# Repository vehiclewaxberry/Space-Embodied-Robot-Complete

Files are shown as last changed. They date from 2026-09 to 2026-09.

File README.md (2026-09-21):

# 航天服务星具身智能机械臂机器人

**Space Service Robot with Embodied Intelligence**

面向在轨服务的 12U 立方星服务星 + B601 六自由度机械臂的完整数字样机、机械/电气设计与自由漂浮动力学证据库。

*A complete digital prototype, mechanical/electrical design package, and free-floating dynamics evidence base for a 12U CubeSat servicing spacecraft with a B601 6-DOF manipulator.*

---

## 项目定位 / Scope

这是一个**在轨服务空间机器人学的科研项目**，同时承载长期硬件研发。两条线互为约束：

- **研究线** —— 面向抓取后可稳定性的**预见式具身抓取**。核心问题：在自由漂浮、刚柔耦合、目标非合作的条件下，捕获策略的可行域由哪些物理边界决定。
- **工程线** —— 可装配、可参数化、可验证的 12U 服务星与 B601 机械设计，作为研究结论的物理载体与参数来源。

研究产出以**机器裁决证据**（`*_gate_check.json`）与论文结构为组织形式，而非演示件。论文规划入口见 [`10_research/paper1_architecture.md`](10_research/paper1_architecture.md)（Paper 1 = 柔性耦合捕获任务可行域），问题树见 [`10_research/research_questions/`](10_research/research_questions/)。

*This is a research project in on-orbit-servicing space robotics, carried alongside long-term hardware development. The research line studies predictive embodied grasping for post-capture stabilizability — specifically, which physical boundaries determine the feasible domain of capture strategies under free-floating, rigid-flexible coupled, non-cooperative conditions. Outputs are organised as machine-adjudicated evidence and paper structure, not demos.*

> **关于历史来源**：项目起源于中国研究生未来飞行器创新大赛（第十二届）。比赛记录、机器 Gate 与负结果作为**历史证据**原位保留，但**比赛期限与比赛交付不再构成研究议程、工程验收门槛或授权 Gate**。请勿据历史比赛记录升级当前结论。

### 任务设定 / Mission

| 项 | 值 |
|---|---|
| 服务星 | 12U CubeSat 平台 |
| 机械臂 | B601，6R 串联构型 |
| 目标 A | 150 kg 翻滚空间碎片 |
| 目标 B | 22 kg 非合作目标星 |
| 动力学工况 | 自由漂浮（free-floating），基座不固定 |
| 研究线 | 面向抓取后可稳定性的预见式具身抓取 |

---

## 仓库导航 / Repository layout

八个业务域，根目录不再建立平行的 `src/` `docs/` `results/` 树。

| 目录 | 内容 |
|---|---|
| [`01_project/`](01_project/) | 项目入口、治理、协作原件、历次工作包记录 |
| [`10_research/`](10_research/) | 研究问题树、方法、合同、知识库、论文材料 |
| [`20_engineering/`](20_engineering/) | **CAD、电气、BOM、参数、接口与设计证据** |
| [`30_simulation/`](30_simulation/) | 模型、程序、测试、原始结果、机器裁决 |
| [`40_evidence/`](40_evidence/) | 图表、媒体、离线展示 |
| [`50_literature/`](50_literature/) | 题录、阅读卡、BibTeX |
| [`70_tools/`](70_tools/) | 编目、展示、校验工具 |
| [`80_third_party/`](80_third_party/) | 外部来源登记与许可（见 [NOTICE.md](NOTICE.md)） |

全项目导航入口：**[PROJECT_MAP.md](PROJECT_MAP.md)**

---

## 协作者快速上手 / Getting started for collaborators

仓库含 **13 GB Git LFS 内容**（7,328 个对象，主要是 CAD）。**克隆方式选错会出问题**，请按下面来。

### ① 先装 Git LFS —— 不装的话你拿到的是一堆占位符

这是最常见的坑：没装 LFS 就 `git clone`，所有 CAD 文件会变成约 130 字节的指针文本。**文件名看着都在，但一个都打不开。**

```bash
git lfs install
```

*Install [Git LFS](https://git-lfs.com/) first. Without it every CAD file clones as a ~130-byte pointer stub — the filenames all look right, but nothing opens.*

### ② 推荐：先不拉 CAD，按需取件

完整克隆会下载 13 GB，**消耗仓库的 LFS 带宽配额**；配额耗尽后**所有人**的 LFS 下载都会被阻断。除非确实需要全部 CAD，否则请用：

```bash
GIT_LFS_SKIP_SMUDGE=1 git clone https://github.com/vehiclewaxberry/Space-Embodied-Robot-Complete.git
```

这样能拿到全部代码、文档、仿真结果与机器裁决（约 256 MB），CAD 先留作指针。需要某个具体部件时再单独拉：

```bash
# 例：只取最新整星总装
git lfs pull --include="20_engineering/SERVICE_STAR_CORE_INSTALLATION_R6H_20260920/**"

# 例：只取某一批 STEP
git lfs pull --include="20_engineering/SERVICE_STAR_HARDWARE_COMPACT_20260921/**"
```

*Full clones pull 13 GB and consume the repository's shared LFS bandwidth quota; once it is exhausted, LFS downloads are blocked for everyone. Prefer the skip-smudge clone above and fetch only what you need.*

### ③ 确实需要全部 CAD 时

```bash
git clone https://github.com/vehiclewaxberry/Space-Embodied-Robot-Complete.git
```

请先知会仓库所有者——这一次操作会占用约 13 GB 带宽配额。

### 打开 CAD 需要什么

| 格式 | 仓库内文件数 | 需要的软件 |
|---|---|---|
| `.STEP` | 3,404 | **任意 CAD 软件**（FreeCAD、Fusion、CATIA、NX…）— 没有 SolidWorks 就用这个 |
| `.SLDASM` / `.SLDPRT` | 6,233 | SolidWorks 2024 及以上 |
| `.FCStd` | 89 | FreeCAD |
| `.glb` / `.stl` | 873 | 任意三维查看器（仅可视化，非设计源） |

全部 CAD 合计 13 GB LFS（7,328 个去重对象——同内容的文件共享一份存储，所以实际下载量小于按文件数的估计）。

---

## 研究线 / Research programme

### 六层架构

研究按六层组织，**各层分别取证，不由某层结论覆盖其它层**：

| 层 | 职责 | 状态 |
|---|---|---|
| **L0** | 任务可行性 / 策略 | 已实现（`sim_10`、`sim_12`） |
| **L1** | SAFE 证据核 | `SAFE-00` 47/47 PASS，`review_status=PENDING_REVIEW` |
| **L2** | 确定性控制 | `CTRL-01/02`，带 PROVISIONAL 范围限定 |
| **L3** | 刚柔世界模型 | `sim_11` v1.1，含占位参数 |
| **L4** | 具身候选生成 | 规划态，未实施 |
| **L5** | 地面验证 | H0–H3 规划态，未实施 |

导航：[`10_research/00_project_architecture/`](10_research/00_project_architecture/)

### 论文线

| 论文 | 主题 | 状态 |
|---|---|---|
| **Paper 1** | 柔性耦合捕获任务可行域 | 证据/查新收口中，结构见 [`paper1_architecture.md`](10_research/paper1_architecture.md) |
| **Paper 2** | 接触带宽 / 保真度 | 候选，未启动 |

问题树 Q1–Q6、理论假设与主张-证据关系见 [`10_research/research_questions/`](10_research/research_questions/)、[`theory_graph/`](10_research/theory_graph/)、[`contribution_map/`](10_research/contribution_map/)。

文献主清单：[`50_literature/references/manifest.yaml`](50_literature/references/manifest.yaml)（44 篇 PDF / 29 张阅读卡；**PDF 全文因版权不随仓库分发**，按 manifest 自行获取）。

### 规划态支线（**尚未授权实施**）

`BRIDGE-UT` 带界不确定目标操作、`Q6-L1` 预制接口装配、On-Orbit Assembly Wave A、Physics-Gated Agent、ROM、VLA —— 这些目录存在**不等于**实施完成或已授权。请按各目录内的具名合同理解其范围。

---

## 当前硬件基线 / Current hardware baseline

这是接手后续开发时**首先要看的**部分。

| 要做的事 | 入口 |
|---|---|
| 四系统硬件主设计（机械 / 电气线束 / 能源热控 / 动力推进） | [`20_engineering/SERVICE_STAR_HARDWARE_COMPACT_20260921/`](20_engineering/SERVICE_STAR_HARDWARE_COMPACT_20260921/) |
| **最新整星总装（数字样机）** | [`SERVICE_STAR_CORE_INSTALLATION_R6H_20260920/native/SERVICE_STAR_SERVICE_R6H.SLDASM`](20_engineering/SERVICE_STAR_CORE_INSTALLATION_R6H_20260920/native/) |
| 电气选型当前指针 | [`20_engineering/SERVICE_STAR_ELECTRICAL_LATEST.json`](20_engineering/SERVICE_STAR_ELECTRICAL_LATEST.json) |
| R7 安装布局草案（**未完成项**） | [`20_engineering/SERVICE_STAR_AUX_STOP_INSTALLATION_R7_20260921/`](20_engineering/SERVICE_STAR_AUX_STOP_INSTALLATION_R7_20260921/) |
| 上游机械来源（星体本体） | [`20_engineering/service_robot_wp03_spacecraft_body_r1/`](20_engineering/service_robot_wp03_spacecraft_body_r1/) |

**读法约定**：选型候选与未安装草案分别看待，**不按目录日期推定完工**。R6H 原件保留，没有回退为早期 WP03。

### CAD 格式说明

原生件为 SolidWorks（`.SLDPRT` / `.SLDASM`），中性交换格式为 `.STEP`，二者均通过 Git LFS 存储。**克隆方式与所需软件见上文[协作者快速上手](#协作者快速上手--getting-started-for-collaborators)**——直接 `git clone` 而未装 LFS 会拿到占位符而非真实 CAD。

---

## 已验证的核心结果 / Verified results

以下数值来自各模块的**机器裁决 JSON**（`*_gate_check.json`），引用时请勿改动。注意：**测试 PASS ≠ 科学 Gate PASS**。

| 编号 | 结论 | 关键数值 |
|---|---|---|
| `sim_05` | B601 自由漂浮，臂运动致基座姿态扰动 | 峰值 **19.20°**；动量守恒 7.3e-17 |
| `sim_06` | 矢量式捕获冲量——**捕获 ≠ 消旋** | 碎片 @3°/s → 捕获后 3.06°/s |
| `sim_07` | ANCF 柔性帆板，点捕获激振 vs 刚性锁定 | ≈ **92×**；振铃 37–75 s |
| `sim_08` | 150 kg 碎片消旋**必须用推力器** | `\|H_c\|` = 3.65 N·m·s = **12×** 轮组容量 |
| `sim_10` | 任务可行域 9000 点四门 fail-closed 扫描 | 裁决 `SIM10_GATES_PASS` |
| `sim_11` v1.1 | 刚柔耦合，有限接触窗口 | `SIM11_GATES_PASS_WITH_PROVISIONAL_PARAMS` |
| `sim_12` Phase1 | 16 例策略证明集——**最优捕获策略是 binding gate 的函数** | `SIM12_PHASE1_GATES_PASS` |
| `SAFE-00` | 运行时安全门 | 47/47 PASS，七绕过面全封 |

### 对后续在轨服务开发的直接含义

1. **基座扰动不可忽略**：自由漂浮下 19.20° 的姿态耦合意味着臂规划必须与姿态控制联合求解。
2. **捕获与消旋是两个问题**：捕获冲量不消除目标角动量；150 kg 级目标的消旋超出轮组容量一个数量级。
3. **柔性帆板是激振主源**：点捕获相对刚性锁定放大约 92 倍，接触策略必须考虑帆板模态。
4. **策略选择依赖于约束边界**：不同 binding gate 下最优策略不同（S1 / S3a / ABORT）。

---

## 明确的未完成项与占位参数 / Known gaps

本节是**刻意保留**的。项目约定：负结果、UNKNOWN 与占位参数不得被整理或总结所掩盖。

| 项 | 状态 | 影响 |
|---|---|---|
| **帆板质量 0.348 kg** | **占位值**。真实面密度 2–5 kg/m²，差 5–10 倍 | 真实参数下「柔性反馈可忽略」的结论**可能翻转**。当前最大硬伤 |
| **接触窗口 `T_c` = 20 ms** | `PROVISIONAL`，待 B601 夹爪实测 | 需替换 `scene_A2_capture.yaml` 后重跑带宽口径 Gate |
| 帆板模态参数 | 占位 | 同上 |
| `e15` ANCF 认证 | 交叉求解最大差 5.64% > 5% 门槛 → `REPEAT_ANCF_CERTIFICATION` | 全耦合新模型须重过该 Gate |
| `FLEX` | `UNKNOWN`，不入 `sim_10` 判据 | 可行域为**刚体边界** |
| R7 安装布局 | 草案，未安装 | 不得按日期推定完工 |
| `CTRL-02` 姿态分账 | `PASS_WITH_PROVISIONAL_SCOPE` | 硬件有效稳定性 `NOT_EVALUATED_NO_ACTUATOR_DYNAMICS` |

> 引用控制类结论时必须带限定语：「**在冻结增益与预注册轨迹下**」。

---

## 证据与结论约定 / Evidence conventions

这套约定是项目的核心工程文化，接手者请遵守：

- **科学结论只认机器裁决 JSON**（`*_gate_check.json`），不认文档摘要。
- **测试通过 ≠ 科学 Gate 通过**。
- 每个 `sim_XX` / `eXX` 模块自带 `src/` `tests/` `results/` `docs/`，自包含。
- 失败、`UNKNOWN`、受限结果**留在原拥有者目录**，不被后续工作覆盖。
- 不同模型与版本的结果**不互相覆盖**，导航不汇总为单一通过状态。
- 目录同名、同日期或位于 `archive/` `_work/` **不足以证明文件无用**。

---

## 复现 / Reproducing

各仿真模块自包含。典型流程：

```bash
cd 30_simulation/sim_11_coupled_dynamics
python -m pytest tests/          # 模块测试
python src/run_all.py            # 重跑场景与 Gate
cat results/sim_11_gate_check.json   # 读机器裁决
```

> **注意**：`control_01` / `control_02` 的 `run_all.py` 会**覆写** `results/` 下的 gate JSON。运行前请先 snapshot，运行后 restore。

---

## 第三方 / Third-party

本仓库**不转发**上游第三方代码库。所使用的外部平台（Basilisk、Exudyn、Chrono、SPART、SpaceDyn、Astrobee、OpenVLA、openpi 等）及其许可证登记于 **[NOTICE.md](NOTICE.md)**，请从各自上游获取。

外部参考 CAD 与供应商模型的来源、版本与许可见 [`80_third_party/README.md`](80_third_party/README.md)。

---

## 引用 / Citation

见 [CITATION.cff](CITATION.cff)。

---

## 许可 / License

见 [LICENSE](LICENSE)。第三方组件各自适用其上游许可，见 [NOTICE.md](NOTICE.md)。

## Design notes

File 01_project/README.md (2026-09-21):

# 项目工作与治理

<!-- WORKSPACE_NAV_START -->
**2026-09-21 目录整理入口：** [本域用途与归档总览](../01_project/governance/WORKSPACE_ORGANIZATION_20260921/WORKSPACE_INDEX.html?domain=01_project) · [全项目导航](../PROJECT_MAP.md)。历史来源和证据原位保留；本轮整理不改变设计或科学结论。
<!-- WORKSPACE_NAV_END -->

2026-09-06 整理。本域保存工作入口、治理记录、人工输入与审阅会话；`competition/` 同时包含历史比赛材料和后续工程工作记录。

- [项目总地图](../PROJECT_MAP.md)：八业务域路径导航。
- [当前整理会话](competition/SERVICE_ROBOT_MECHANICAL_CONSOLIDATION_20260905/CURRENT_candidate.md)：问题、依赖、运行与文件整理账本。
- [R2 来源指针](current/CURRENT_RELEASE_POINTERS_V1.yaml)与[来源关系索引](current/PROJECT_CURRENT_AUTHORITY_V1.yaml)：定位原始记录；派生导航不替代机器证据。
- [工程候选入口](../20_engineering/README.md)：WP03 服务星候选与工程来源。
- [工作与历史材料](competition/README.md)、[治理迁移记录](governance/README.md)、[人工输入](inbox/)：按日期和对象阅读。
- [根层历史综述](competition/archive/ROOT_HISTORY_20260729_20260810.md)：原根总结与入驻说明已合并；[入驻独有图示](competition/archive/onboarding_20260729/)及[历史收尾记录](competition/archive/90_competition_closeout/)保留原字节。

本域不承载科学仿真结果。`current/` 的日期快照和旧任务许可保留原语境，不能把历史“当前”当作今天的授权。原重复导航段已吸收，整理前字节保存在共享 SQLite。

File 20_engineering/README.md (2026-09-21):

# 工程设计、参数与装配入口

<!-- WORKSPACE_NAV_START -->
**2026-09-21 目录整理入口：** [本域用途与归档总览](../01_project/governance/WORKSPACE_ORGANIZATION_20260921/WORKSPACE_INDEX.html?domain=20_engineering) · [全项目导航](../PROJECT_MAP.md)。历史来源和证据原位保留；本轮整理不改变设计或科学结论。
<!-- WORKSPACE_NAV_END -->

整理日期：2026-09-21。本域保存当前机械候选、被引用的上游模型、参数和历史验证来源。先按以下入口阅读；目录名中的 RELEASE、FINAL 或版本号不能独自证明工程完成或可制造。

**硬件设计的精简工作入口为 [SERVICE_STAR_HARDWARE_COMPACT_20260921](SERVICE_STAR_HARDWARE_COMPACT_20260921/README.md)。其中当前服务态总装以R6H为准，保留后续水平安装集成，并包含机械、电气线束、能源热控和推进主文件。原R6H总装未删除；WP03属于上游机械基线，不能替代R6H。整理状态与公开边界见包内说明。**

## 当前设计与装配

| 内容 | 入口与职责 |
|---|---|
| 当前硬件精简副本 | [硬件设计总入口](SERVICE_STAR_HARDWARE_COMPACT_20260921/README.md)：R6H机械总装及电气、热控、推进主设计 |
| 当前机械源总装 | [R6H原生服务态总装](SERVICE_STAR_CORE_INSTALLATION_R6H_20260920/native/SERVICE_STAR_SERVICE_R6H.SLDASM)、[现行指针](SERVICE_STAR_CORE_INSTALLATION_LATEST.json) |
| 上游完整机械基线 | [WP03](service_robot_wp03_spacecraft_body_r1/README.md)：星体、完整 B601、双翼、保持器、设备接口和总装图册；保留其来源职责 |
| 装配和实际交付范围 | [装配程序](service_robot_wp03_spacecraft_body_r1/ASSEMBLY_SEQUENCE.md)、[交付回执](service_robot_wp03_spacecraft_body_r1/results/DELIVERY_RECEIPT.json) |
| 仍被 WP03 读取的上游 | [WP01](service_robot_wp01_20260905/)与[WP02](service_robot_wp02_20260905/)：机械臂、根框、接触、线束及检查输入；不是三套可互换的当前整星 |
| 参数和接口 | [config](config/)、[design_inputs](design_inputs/)、[parameter_registry](parameter_registry/)：按各模型所属版本使用 |
| 原生 CAD 和厂家/accepted 来源 | [cad](cad/)；保留 donor、冻结基线和原生装配引用关系 |
| 审阅与系统材料 | [design_review](design_review/)、[system_design](system_design/)、[automation](automation/) |

## R2 与早期版本的职责

- [R2 原终裁](MECHANICAL_ENGINEERING_RELEASE_R2/00_RELEASE_GATE.json)与[基线清单](MECHANICAL_ENGINEERING_RELEASE_R2/01_BASELINE_MANIFEST.json)独立描述 R2；不被 WP03 候选覆盖。
- R2 后续具名记录由[发布来源指针](../01_project/current/CURRENT_RELEASE_POINTERS_V1.yaml)定位，包括 [ODR-60 Option A](MECHANICAL_ENGINEERING_RELEASE_R2/_work/odr/ODR60_OPTION_A_EXECUTION_CLOSURE_V1/results/ODR60_OPTION_A_EXECUTION_CLOSURE_GATE_V1.json)。
- `F3*`、`F4*`、`F5*` 的版本树包含 donor、失败几何、冻结输入和验证链。旧导航所称 M7“当前”仅指当时记录；其 [V5 continuation Gate](F3R2_M7_MECHANICAL_FINAL_DESIGN_CLOSURE_V1/ecr_b601_harness_rated_envelope/15_loop_continuation_v5/MECHANICAL_LOOP_ENGINEERING_CONTINUATION_GATE_V5.json)原结论为 HOLD，不覆盖本页 WP03 入口。
- 27 个 `_MFINAL_G0_SMOKE_*` 目录共 83 个 JSON，是旧会话/连接核查回执；已有历史脚本按路径读取，集中在索引中作为回执组查看。目录多不表示存在 27 套机械设计，本轮保持路径和证据身份。
- [Stage 1 早期库](stage1_spacecraft_layout/README.md)包含早期参考、布局需求、坐标和预算模板。已合并三组中英文需求、一份建库说明和一份英文资产镜像；适配器英文原件因 A4 清单固定 SHA 保留。
- [原根结构材料](system_design/legacy_root_structure/)保留合同原值和独立职责。

## 缓存、压缩包与重复件为什么有些保留

WP01/02/03 的 `__cadgen__` 编目分别为 4,132 / 1,368 / 8,454 文件，合计 **13,954**。这些是 CAD 可视化/拓扑派生物及诊断来源，数量不等于设计零件数。已查 WP03 的 Python 生成视图包与 STEP 导入视图包具有不同 stepHash 和网格参数；[包络方法比较](service_robot_wp03_spacecraft_body_r1/results/BOUNDING_METHOD_COMPARISON.json)固定了 assembly、542 个组件 GLB 和 topology GLB 的输入身份。交付汇总与图册脚本也读取这些包，已有 PNG 或 STEP 不足以证明它们全部可删除。

工程域剩余 11 个 ZIP 为 9 个 B51 授权/阶段包、1 个原终端基线包、1 个 V5 失效模型隔离包。它们不是 11 份同字节文件；其中已检查的基线包和隔离包被回执固定 SHA/范围，保留原始包。来源许可、O11/O13、PHASE0 等相同正文的 donor 副本也有 source/copy 分别绑定的情形，不能只保留一份后仍声称原验证链完整。

Route-C V8 第 1 回路简报的冗余副本已删除，保留 [规范简报](MECHANICAL_ENGINEERING_RELEASE_R2/route_c/B601_ROUTE_C_V8_CAD_BRIEF.md)；该回路的被拒绝模型、构建器、JSON 和网格证据仍在原处。

已从 WP01/WP02/WP03 删除 159 个对应源码存在、文件头匹配且未发现固定输入绑定的 Python 字节码，源码均保留。审阅的其余 197 个缓存保持原位；12 个删除文件后已空的缓存目录因自动审批拒绝删除而保留。未执行冷启动或重新编译来宣称重建通过。

## 全域记录

[统一整理入口](../01_project/competition/SERVICE_ROBOT_MECHANICAL_CONSOLIDATION_20260905/CURRENT_candidate.md)连接逐文件目录、处置理由、删除映射及原始字节备份。对目录和文件用途的登记不等于逐件打开 CAD、验证全部动态引用或全文专业精读；这些范围在账本中分别标记。

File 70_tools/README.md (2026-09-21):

# 项目整理、研究环境与展示工具

<!-- WORKSPACE_NAV_START -->
**2026-09-21 目录整理入口：** [本域用途与归档总览](../01_project/governance/WORKSPACE_ORGANIZATION_20260921/WORKSPACE_INDEX.html?domain=70_tools) · [全项目导航](../PROJECT_MAP.md)。历史来源和证据原位保留；本轮整理不改变设计或科学结论。
<!-- WORKSPACE_NAV_END -->

导航整理：2026-09-06。本域保存非业务结论型工具；工具运行记录与原始科学、工程结论分开。

- [全项目文件目录工具](mechanical_asset_index/scan_service_robot_assets.py)：使用 `--full-project` 转入[静态目录解析器](mechanical_asset_index/full_project_catalog.py)，登记文件、依赖、阅读范围与整理处置。
- [统一目录数据库](../01_project/competition/SERVICE_ROBOT_MECHANICAL_CONSOLIDATION_20260905/runs/loop0_20260905/screening/full_project_catalog.sqlite)：保存本轮目录、阅读记录、逐文件审阅、操作及压缩前件备份；[会话入口](../01_project/competition/SERVICE_ROBOT_MECHANICAL_CONSOLIDATION_20260905/CURRENT_candidate.md)。
- [来源索引构建器](current_authority_index/README.md)：生成 R2 等既有来源的派生导航。
- [研究仪表板](research_dashboard/README.md)与[可视化源码](project_visualization/src/)：构建离线展示，不新增科学结论。
- [科研环境说明](research_env/README.md)：工具链的有日期记录，软件能力及安装情况按实际环境核实。

在项目根目录运行全项目静态编目，或读取已存摘要：

```powershell
python -B 70_tools/mechanical_asset_index/scan_service_robot_assets.py --full-project
python -B 70_tools/mechanical_asset_index/scan_service_robot_assets.py --full-project --summary
```

这些入口不执行仿真或 CAD 生成。文件整理的操作范围和结果由本轮会话及数据库记录，不由旧索引中的删除候选数量决定。

- [根级 F3R2 历史脚本](legacy_f3r2_root_scripts/)已归入本域；它们与发布包 99_tools 的同名版本不同，固定输入哈希保留。旧辅助模块缺失仍是已知历史问题。
- [本次根目录合并工具](mechanical_asset_index/consolidate_root_layout.py)与 SQLite `root_layout_actions` 保存已执行映射；该工具为已完成的一次性操作，不作为日常 CAD/仿真入口。`--full-project` 是原编目快照的续跑，不是目录迁移后的全新扫描。

## 子目录职责

| 子目录 | 用途与保留范围 |
|---|---|
| [current_authority_index/](current_authority_index/README.md) | 派生来源导航生成器及其独立测试；不拥有机器结论 |
| [mechanical_asset_index/](mechanical_asset_index/) | 本次全项目编目与整理工具；由主线程维护 |
| [legacy_f3r2_root_scripts/](legacy_f3r2_root_scripts/) | 已归位的历史 F3R2 脚本，固定输入与旧版本差异保留 |
| [preauthorization_readiness/](preauthorization_readiness/unified_r2_v2/README.md) | Unified R2 历史预执行探测与就绪性检查，保留对应源码与记录 |
| [project_visualization/](project_visualization/) | VIZ 离线展示源码与独立验证；[历史比赛启动说明](../10_research/competition_convergence/launch_manifest.md) |
| [research_dashboard/](research_dashboard/README.md) | P0 历史研究证据集成；报告和输入/产物清单相互绑定，原位保留 |
| [research_env/](research_env/README.md) | 有日期的软件环境与工具能力记录，不是科学参数或当前安装保证 |

旧域说明中的重复导航已并入本页。报告构建、可视化和回放从本域进入；本轮不重写工具包的冻结 Gate、结果 manifest 或输入哈希。

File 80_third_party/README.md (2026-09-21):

# 第三方代码、供应商与参考资源

<!-- WORKSPACE_NAV_START -->
**2026-09-21 目录整理入口：** [本域用途与归档总览](../01_project/governance/WORKSPACE_ORGANIZATION_20260921/WORKSPACE_INDEX.html?domain=80_third_party) · [全项目导航](../PROJECT_MAP.md)。历史来源和证据原位保留；本轮整理不改变设计或科学结论。
<!-- WORKSPACE_NAV_END -->

导航整理：2026-09-06。本域保存外部代码、参考平台和供应商资源；外部来源与项目自有设计、计算结果分开。

- [外部参考工程和资料](external/)：按来源、版本和实际消费者定位。
- [供应商及第三方仓库](vendor/)：保留各仓库的许可证、独立版本历史和本地修改信息。
- [文献题录](../50_literature/README.md)：论文进入文献库；[工程定义](../20_engineering/README.md)负责本项目使用这些资料形成的设计。

许可证与 NOTICE 以对应来源中的实际文件为准；旧导航所述待建目录不视为已存在。第三方参考或演示结果不自动成为本项目结论。

旧导航中的 `notices/` 是待建的项目随行许可证、NOTICE 与来源哈希记录目录；该规划不代表目录或第三方源资产副本已经存在。

## BIRDSX-CAD 来源入口

优先使用 [birds/BIRDSX-CAD](external/spacecraft_layout_refs/birds/BIRDSX-CAD/) 的完整来源与 [README](external/spacecraft_layout_refs/birds/BIRDSX-CAD/README.md)。[birdsx/BIRDSX-CAD](external/spacecraft_layout_refs/birdsx/BIRDSX-CAD/) 保留为已有消费者使用的历史镜像，两处属于同一上游来源，不应计作两份独立工程参考。

2026-09-06 本地核验：两库 HEAD 均为 `36bceeacc9f899477f2f10e36f8a65f7b58cb4ed`，共有的 26 个工作树文件逐项 SHA-256 相同；`birds` 工作树完整且干净，`birdsx` 存在原有 `README.md` 删除状态。两库的独立 `.git` 索引与日志有差异，因此各自版本历史和原有工作树状态完整保留。许可证见 [BIRDSX-CAD/LICENSE](external/spacecraft_layout_refs/birds/BIRDSX-CAD/LICENSE)，历史镜像内也保留原许可证。

## LibreCube 接口参考范围

LibreCube 用作模块化开源空间系统的接口思想参考。原第一阶段说明约定暂不深入代码，仅在需要 OBC、EPS 或模块接口定义时再展开；这是原阶段的范围记录，不构成新的实施授权。现有 [LC2102 源库](external/spacecraft_layout_refs/librecube/LC2102/) 与其许可证、版本历史继续保留。

2026-09-06 将原 `external/spacecraft_layout_refs/librecube_notes/README.md` 的三条说明并入本节，并移除该空目录；原文完整字节保存在整理账本的 SQLite 快照中。此次元数据与目录核验不等同于第三方代码、CAD 原生内部引用或论文全文的专业审查。

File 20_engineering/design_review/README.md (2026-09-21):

# Mechanical Design Reviews

本目录保存机械系统设计评审包，不保存 SolidWorks 原生模型，也不替代科学 Gate。

当前入口：

- [V2 System Mechanical Preliminary Design Review](./V2_PDR_package/README.md)

评审阶段与 CAD 输出严格分离：

```text
B2.5 controlled design inputs
  -> B2.8 preliminary mechanical design and PDR
  -> named human B3 authorization
  -> independent V2 SolidWorks root
```

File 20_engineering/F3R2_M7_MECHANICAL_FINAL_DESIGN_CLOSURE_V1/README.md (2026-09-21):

# F3R2 M7 Mechanical Final Design Closure V1

Owner-directed loop (directive dated 2026-08-21/22): close every internally
closable mechanical-design HOLD and drive the product to

    MECHANICAL_ENGINEERING_DESIGN_RELEASED   (Gate A)

while keeping

    MECHANICAL_FLIGHT_QUALIFICATION_RELEASED (Gate B) = HOLD

This loop converts the wide, shallow M4/M5/M6 candidate assets into a narrow,
deep, source-bound product definition: geometry, configurations, design mass
model, materials, tolerance allocation, fasteners, mechanisms, harness,
operational loads, operational structural verification, drawings, BOM, and the
MECH-RL interface.

## Owner decisions frozen this loop

See `00_authority/M7_OWNER_DECISION_REGISTER_V1.yaml` (ODR-01..ODR-06),
including: M-frame authority = T_SM=[185.25,0,0] mm + Ry(90°); panel failure =
attached-stuck, never jettison unless a jettison mechanism is later designed;
SolidWorks native line permanently off critical path; native V5 gripper
interference findings superseded by neutral R1 authority; M3R 0.7619 kg =
design-budget authority; operational-loads FEA authorized, launch-qualification
FEA remains HOLD (no launcher ICD).

## Layout

- `00_authority/` — owner decisions, phase boundary, execution plan
- `wp1_structure_cad/` — product structure, design-freeze assembly, harness routing
- `wp2_design_mass/` — nine-configuration DESIGN mass/CoM/inertia model
- `wp3_tolerance_alloc/` — 14-chain tolerance allocation
- `wp4_fastener_design/` — M3R + product fastener design and schedules
- `wp5_mechanisms/` — HDRM / solar hinge / gripper engineering packs
- `wp6_material_selection/` — DESIGN_APPROVED material register
- `wp7_fea_operational/` — operational structural verification (Abaqus batch)
- `wp8_thermal/` — thermo-elastic ΔT sensitivity envelopes
- `wp9_release_package/` — drawings, BOM V3, schedules, assembly, inspection
- `wp10_mech_rl_v4/` — dynamics/RL interface upgrade
- `12_release/` — M7 gate, manifest, Gate A scorecard, summary
- `99_tools/` — builders, validators, solver probes

## Standing rules (unchanged from M4–M6)

Fail-closed; no zero-fill; candidate≠authority; design≠flight-qualified;
unknowns stay null+HOLD where a physical/external input is genuinely absent;
L0 URDF masses never overridden; launch qualification stays HOLD; every
artifact carries schema/generated_local/source_register with SHA-256 pins.
FreeCAD: single-process Owner Override (WP1 only). Abaqus: batch-only,
no CAE GUI, model sizes bounded by the failed 6 GiB memory gate
(available ≈1.3 GiB at loop start).

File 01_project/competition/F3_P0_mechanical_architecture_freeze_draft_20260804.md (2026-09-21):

# F3-P0 B601 制造级机械架构冻结草案

> 文档编号：`F3-P0-DRAFT-20260804`
> 生成 UTC：2026-08-04
> 状态：`PDR_STAGE_PLANNING_DRAFT` — **不构成 CAD 授权，不启 CAD_AUTHORING**
> 路径裁决：用户在状态差异报告后选择**路径 A（状态校正 + 草案）**
> 真值基线：`AGENTS.md` / `spacecraft-mechanical-design-agent.md` / `asm_00_gate_check.json` / `phase0_completion_record.json`
> 上一阶段：`NATIVE01_PHASE1_BUILT_PASS`（V2_3 SolidWorks 原生，2026-07-27 冻结）

---

## 0. 状态校正（必读，否则后续章节前提错位）

### 0.1 用户 F3 启动前提与仓库机器状态的差异

| 检查项 | 用户前提 | 仓库实际 | 处置 |
|---|---|---|---|
| FreeCAD `.FCStd` 文件 | 已存在并验证 | **0 个**（仅 80_third_party/librepcb 等无关第三方） | 路径 A：不依赖 FreeCAD |
| F0/F1/F2 阶段报告 | 已 PASS | **0 份**，全文搜索零命中 | 路径 A：不引用 F0-F2 |
| CAD 工具链 | FreeCAD 制造级 | SolidWorks V2_3_NATIVE_INTEGRATION（47 零件 + 8 子装配） | 以 SolidWorks 真值继续 |
| `spacecraft-mechanical-design-agent.md` | F3 已授权 | `CAD_AUTHORING：当前禁用` | 路径 A：本草案仅在 `V2_ARCHITECTURE` / `CAD_ENTRY_REVIEW` 模式下产出 |
| `.codex/AGENTS.md` | F3 已授权 | `V2 CAD NOT_AUTHORIZED`；HAG-A 前 `PLANNED_NOT_AUTHORIZED` | 同上 |
| `asm_00_gate_check.json` | F3 已授权 | `HAG-A: ABSENT`；`scientific_execution_authorized: false` | F3-P0 不动 asm_00 裁决 |

### 0.2 本草案的允许边界

允许：
- 阅读、引用、对照现有 V2_3 SolidWorks 文件、URDF、配置、Gate JSON；
- 产出 PDR 阶段架构规划文档（本文）；
- 在文档中显式登记未来 F3-A..F3-E 的工作项、参数缺口、接口冻结需求；
- 标注"待 HAG-F3 授权"的具体动作清单。

禁止（本草案不做）：
- 创建、修改、保存任何 `.SLDPRT` / `.SLDASM` / `.FCStd` / `.step` / URDF / config / Gate JSON；
- 推断或捏造材料、板厚、紧固件、载荷、刚度、强度、模态数值；
- 自签 HAG-F3 或任何下一阶段 Gate；
- 改写 `20_engineering/config/geometry/`、`30_simulation/`、`40_evidence/` 冻结内容；
- 把"路径 A 草案"当作"F0-F2 PASS"的证据链入口。

### 0.3 升级路径

本草案在以下任一条件满足后才可升级为 F3-P1 实施合同：
1. 真实 F0-F2 FreeCAD 工作入库并通过哈希核验（路径 B）；
2. 用户签发具名 `HAG-F3-P1-CAD_AUTHORING.yaml` 显式授权 SolidWorks 或 FreeCAD 原生改写（路径 C 的 P1 版本）；
3. HAG-A 落地后 asm_00 解除 AG0 阻塞（影响 F3-C 接触资格子线）。

在此之前，F3-A..F3-E 所有"建模"动作为 `PLANNED_NOT_AUTHORIZED`。

---

## 1. 当前 V2_3 SolidWorks 原生装配真值

### 1.1 顶层装配树（已冻结，源=V2_2_NATIVE，108 文件 sha256 锁定）

```
Space_Embodied_Service_Spacecraft_V2_2.SLDASM
├── 00_Master_Skeleton_V2_2.SLDPRT            18 基准面 + 3D 包络草图 + 34 参数属性（零实体）
├── 01_Primary_Structure_V2_2.SLDASM          (7 子装配)
│   ├── Front_End_Frame / Rear_End_Frame      环框（4×17×17 横梁，纵梁间端接）
│   ├── Front_Transverse_Frame                X 119..125
│   ├── Mid_Transverse_Frame_1 / _2           X ±(58..64)
│   ├── Longerons_4X.SLDPRT                   4 根 17×17，角点 ±101.65，X -183..183
│   └── Equipment_Decks.SLDASM (3)            前/中/后舱甲板 z -40..-36
├── Removable_Panels.SLDASM (6)               ±Y 前后分缝 ×4 + ±Z ×2，3mm，外表面齐平 113.15
├── 02_B601_Mount_and_Load_Path.SLDASM (8)    扩散板→前端框→法兰→160×160×12 适配板→Ø110 导向凸台
│                                             + 双载荷桥 + 线束通道 + 内维修盖
├── 03_B601_Three_Representations.SLDASM      三表示总装（部分已建，见 §1.2）
├── 04_ARM_STOW_SUPPORT.SLDASM (5)            上臂/前臂/腕鞍座（接触高 234.77/248.49/253.80 实测）
│                                             + 发射锁参考 + 释放净空包络
├── 05_Solar_Array_Root_Left.SLDASM (9)       SC 侧支座 + 前后铰链耳（带 Ø8.4 销孔）+ 销包络
└── 06_Solar_Array_Root_Right.SLDASM (9)      + 翼板侧叶片 + 机械止挡 + HDRM 座 + 释放机构包络
                                              + 线束服务环
```

零件 47 个、装配 8 个、断链 0、重复装入 0。每个零件带 `ROLE / STATUS / OWNER / PARENT_ASSEMBLY / GEOMETRY_AUTHORITY / MASS_AUTHORITY / STRENGTH_AUTHORITY / BLOCKED_CONSUMERS` 自定义属性。

### 1.2 B601 三表示当前状态（关键）

| 表示 | 目录 | 状态 | 文件数 | 备注 |
|---|---|---|---|---|
| `B601_KINEMATIC_PROXY` | `03_B601_Three_Representations/B601_KINEMATIC_PROXY/` | **已建** | 21 | 10 × `B601_PROXY_*.SLDPRT` + 10 × `PROXY_*.SLDPRT`（双命名） + 1 SLDASM；运动学代理，来自 accepted URDF 几何 |
| `B601_MASS_SURROGATE` | `03_B601_Three_Representations/B601_MASS_SURROGATE/` | **已建** | 11 | 10 × `MASS_*.SLDPRT` + 1 SLDASM；质量代理，URDF inertial 包络化 |
| `B601_STOWED_HIFI` | `03_B601_Three_Representations/B601_STOWED_HIFI/` | **空目录** | 0 | `phase0_completion_record.json` 明示 `CONFIRMED_NOT_CREATED`；待导入 35 MB 厂商 STEP `reBot_B601_DM_v1.1_20260425.step`，该操作有失败史（headless LoadFile4 无返回，215 s 超时） |

**三表示策略**（来自任务书）：HIFI = 真实厂商几何用于收拢态可视化与干涉；KINEMATIC_PROXY = FK 碰撞体用于配置切换；MASS_SURROGATE = URDF 质量分布的体积占位，**不参与质量真值**（mass=EXCLUDED，URDF 4.6956 kg 唯一）。

### 1.3 已冻结的关键数值（引用时勿改）

| 项 | 值 | 来源 | 备注 |
|---|---|---|---|
| `T_SM` 名义冻结 v1 | t=[185.25,0,0] mm，R=R_y(+90°) | `coordinate_frame_definition_v0.md` §3.1 | 动力学轨；显示轨 `MOUNT_FACE_X=198`，双轨冲突 `T_SM_TRACK_CONFLICT` 未裁决 |
| 适配板尺寸 | 160×160×12 mm，Ø100 中央凸台高 15 mm | `arm_mount_v1.yaml` / V22 报告 §1 | |
| B601 总动力学质量 | 4.6956 kg（臂 4.4293 + 夹爪 0.2665） | `arm_b601_v1.yaml` | HYBRID 来源；URDF 唯一真值，CAD 不得覆盖 |
| 服务星 12U 质量 | 24.0 kg（v0）/ 23.30 kg（v1 bus only） | `mass_inertia_budget_v1.csv` | `confidence: low` |
| 目标星质量 | 22.0 kg | 同上 | `confidence: low` |
| 碎片质量 | 150.0 kg | 同上 | `confidence: low` |
| 收拢向量 v3 | clock=25°，q_deg=[145.572,-168.000,-57.000,-41.143,-20.954,-3.000] | `O13_STOW_VECTOR_V3_REPORT.md` | `STOW_VECTOR_STATUS=CANDIDATE_HOLD`，几何间隙 15.56 mm PASS，接触资格未定 |
| 三鞍座站位 | Aft X[-20,0] z=261.08 / Mid X[80,100] z=214.92 / Fwd X[160,180] z=209.42 | `design/o13_saddle_stations.json` | 塔高 147.93/101.77/96.27，全 ≤150 mm |
| C5 收拢超宽 | 238.3 mm > 226.3 mm，超 12.0 mm | `CODEX_CONTINUATION_RECONCILIATION.md` §3 | `NEGATIVE_PRESERVED_NOT_CLOSED`，禁止隐藏/减薄/移动制造假通过 |
| 翼根机构下限宽 | 302.3 mm（双侧达 \|Y\|=151.15） | 同上 | 不可消解，登记入 Master Skeleton |
| 收拢态 Z 上限 | UNKNOWN | V22 报告 §4.1 | 臂顶 z=359.02 高出整星盒顶 245.87 mm，无判据可判合规 |

### 1.4 已登记的未消解 HOLD

1. `T_SM_TRACK_CONFLICT` — 动力学 185.25 vs 显示 198，未裁决；
2. `STOW_VECTOR_STATUS = CANDIDATE_HOLD` — 几何 PASS 但接触资格未定（垫材料、预紧、发射载荷、B601 壳体承载能力）；
3. `STOW_Z_LIMIT_REFERENCE = UNKNOWN` — 收拢态高度无判据；
4. `B601_STOWED_HIFI` 未建 — 厂商 STEP 导入失败史；
5. C5 翼板超宽 12 mm — 翼板本体不在 V2_3 范围；
6. 翼根机构下限宽 302.3 mm — 不可消解；
7. 25° 时钟角 — 人工批准但比较配置并存；
8. `O11 ARM-STOW X 站位差异` — Codex [40,90]/[-150,-110] vs V2_3 [10,60]/[-100,-40]，随时钟角裁决；
9. 材料、强度、公差、紧固件、热、FEA、动力学 — 全部未定义/未运行；
10. `HAG-A ABSENT` — asm_00 AG0 BLOCKED，影响 F3-C 接触资格物理分支。

---

## 2. F3 愿景与 V2_3 现实的映射

用户 F3 愿景分 5 条并行线（F3-A..F3-E）。下表把每条线映射到 V2_3 现状，识别"已存在 / 部分存在 / 全新"。

| F3 子线 | 用户目标 | V2_3 现状 | 缺口性质 | F3-P0 处置 |
|---|---|---|---|---|
| **F3-A** B601 本体深化 | 关节壳体 + 输出承载 + 关节接口 + 线束 | KINEMATIC_PROXY（URDF 几何）+ MASS_SURROGATE（URDF 质量包络）；HIFI 空目录 | **HIFI 未建**；无关节壳体/轴承座/螺栓圈/线束通道 | §3 结构树 + §4 BOM + §5 参数表，标注待授权 |
| **F3-B** 连杆制造设计 | 壳体 + 端接 + 加强筋 + 线束通道 + 维护盖 | KINEMATIC_PROXY link1..6 为 URDF mesh 包络，无制造特征 | **无制造级连杆** | §3 结构树，标注为 F3-A 完成后顺序项 |
| **F3-C** 收拢/释放机构 | G07 主鞍座 + G08 腕部支撑 + 6DOF 载荷路径 | `04_ARM_STOW_SUPPORT` 已有 Fwd/Mid/Aft 鞍座 + 发射锁参考 + 释放净空包络 | **接触垫/预紧/阻尼/二级止挡未定义**；CANDIDATE_HOLD | §6 载荷路径图，标注接触资格待 HAG-A + 实测 |
| **F3-D** HDRM | latch + 释放作动器 + 预紧弹簧 + 状态传感器 + 机械止挡 | 帆板侧 HDRM 已有（HDRM_Base/Rod ×2 每侧）；**机械臂侧 HDRM 无** | **机械臂收拢 HDRM 全新** | §3 结构树标注为 F3-C 完成后顺序项；功能包络而非飞行型号 |
| **F3-E** 末端执行器 | EE-V1 接口级 / V2 柔顺捕获 / V3 非合作目标 | URDF gripper_link + left/right fingers（运动学）；无 F/T 法兰/相机座/柔顺关节 | **EE-V1/V2/V3 全新** | §3 结构树标注为 F3-A/B 完成后顺序项；V1+V2 为比赛优先 |

**关键发现**：用户的 F3 愿景并非"从零开始"，而是把 V2_3 的"运动学/质量代理 + 结构骨架"升级为"制造级数字样机"。最大的单点缺口是 **B601_STOWED_HIFI 未建**——这是 F3-A/B/C/D/E 所有子线的高保真几何前提。

---

## 3. 交付物 1：B601 制造级结构树（规划态）

按用户指定的"载荷路径 → 接口 → 关节 → 连杆 → 末端 → 控制模型"顺序组织。**本结构树为规划态，不创建任何文件**。

### 3.1 B601 制造级结构树（拟建，标注现有/新建）

```
B601_MANUFACTURING_GRADE (拟建顶层，F3-P1 授权后创建)
│
├── [EXISTING] 00_Master_Skeleton_V2_2.SLDPRT
│   └── 继承 V2_3，零实体，34 参数属性；F3 增量：关节限位/线束包络/接触垫参数
│
├── [EXISTING - PARTIAL] 01_Primary_Structure (服务星主结构，非 B601)
│   └── 继承 V2_3；F3 不动主结构，仅核对 B601 接口面
│
├── [EXISTING] 02_B601_Mount_and_Load_Path (8 件)
│   ├── Adapter_Plate.SLDPRT                    160×160×12 适配板
│   ├── Central_Boss.SLDPRT                     Ø100×15 中央凸台
│   ├── Spacecraft_Flange.SLDPRT                航天器侧法兰
│   ├── Load_Spreading_Frame.SLDPRT             载荷扩散板
│   ├── Load_Bridge_Left/Right.SLDPRT           双载荷桥
│   ├── Harness_Passage.SLDPRT                  线束通道
│   └── Maintenance_Access_Cover.SLDPRT         维修盖
│   F3 增量：螺栓圈/定位销/PCD/基准面（参数表 §5）
│
├── [TO_BUILD] 03_B601_Manufacturing_Body (B601 本体深化，F3-A 主体)
│   │
│   ├── [TO_BUILD] B601_STOWED_HIFI (高保真，35 MB 厂商 STEP 导入)
│   │   └── 拟来自 reBot_B601_DM_v1.1_20260425.step
│   │
│   ├── [TO_BUILD] Joint_Housing_Assembly ×6 (J1..J6)
│   │   ├── Joint_Housing_Main.SLDPRT          主承力壳体（Al 7075-T6 候选）
│   │   ├── Joint_Reinforcement_Rib.SLDPRT      加强筋
│   │   ├── Joint_Mounting_Boss.SLDPRT          安装凸台
│   │   ├── Joint_Flange.SLDPRT                 法兰面
│   │   ├── Joint_Inspection_Cover.SLDPRT       检修盖
│   │   ├── Joint_Thermal_Mount_Area.SLDPRT     热控安装区域
│   │   ├── Bearing_Seat.SLDPRT                 轴承座
│   │   ├── Output_Flange.SLDPRT                输出法兰
│   │   ├── Bolt_Circle.SLDPRT (参考)           螺栓圈
│   │   └── Positioning_Feature.SLDPRT (参考)   定位结构
│   │
│   ├── [TO_BUILD] Output_Bearing_Structure ×6
│   │   载荷路径：电机 → 减速器 → 输出轴 → 轴承 → 法兰 → 连杆
│   │   └── Bearing_Housing / Output_Shaft / Bearing_Set / Flange_Bolt_Pattern
│   │
│   ├── [TO_BUILD] Joint_Interface ×6
│   │   └── 每关节输出 JOINT_INTERFACE_CONTROL_DOCUMENT（§5 参数表）
│   │
│   └── [TO_BUILD] Joint_Wiring ×6
│       ├── Connector.SLDPRT
│       ├── Cable_Routing_Channel.SLDPRT
│       ├── Strain_Relief.SLDPRT
│       └── Joint_Rotation_Envelope.SLDPRT（验证 qmin/qmax 下线束不被拉伸/折死/穿轴）
│
├── [TO_BUILD] 04_Link_Manufacturing (F3-B，10 连杆制造级)
│   │   注：B601 6R 有 6 link（base_link + link1..6 + gripper_link）；用户"10 links"对应 V2_3 已含的 10 carrier + J00-J09，需在 F3-P1 核对数量口径
│   │
│   ├── Link_Shell.SLDPRT ×N              壳体（CFRP/Al 候选）
│   ├── Link_Upper_Flange.SLDPRT ×N       上端金属端接
│   ├── Link_Lower_Flange.SLDPRT ×N       下端金属端接
│   ├── Link_Reinforcement_Rib.SLDPRT ×N  加强筋
│   ├── Link_Harness_Channel.SLDPRT ×N    内部线束通道
│   └── Link_Maintenance_Cover.SLDPRT ×N  维护盖
│   每连杆输出 LINKxx_MANUFACTURING_REPORT.md（材料/质量/URDF 对应/制造方法/接口/刚度/模态候选/维护）
│
├── [EXISTING - PARTIAL] 05_ARM_STOW_SUPPORT (F3-C，5 件已建，需补接触资格)
│   ├── Aft_Saddle.SLDPRT                    X[-20,0] z=261.08 塔高 147.93
│   ├── Mid_Saddle.SLDPRT                     X[80,100] z=214.92 塔高 101.77
│   ├── Fwd_Saddle.SLDPRT                     X[160,180] z=209.42 塔高 96.27
│   ├── Launch_Lock_Interface_Reference.SLDPRT   发射锁参考
│   └── Release_Clearance_Envelope.SLDPRT        释放净空包络
│   F3 增量（G07/G08）：
│   ├── [TO_BUILD] Guide_Cone.SLDPRT              导向锥面
│   ├── [TO_BUILD] Contact_Pad.SLDPRT             接触垫（材料待定）
│   ├── [TO_BUILD] Lateral_Limiter.SLDPRT         横向限位
│   ├── [TO_BUILD] Axial_Hard_Stop.SLDPRT         轴向挡块
│   ├── [TO_BUILD] Preload_Mechanism.SLDPRT       预紧结构
│   ├── [TO_BUILD] Primary_Stop.SLDPRT            G08 主止挡
│   ├── [TO_BUILD] Secondary_Stop.SLDPRT          G08 备用止挡
│   ├── [TO_BUILD] Preload_Spring.SLDPRT          G08 预紧弹簧
│   └── [TO_BUILD] Damping_Element.SLDPRT         G08 阻尼元件
│
├── [TO_BUILD] 06_ARM_HDRM (F3-D，机械臂收拢 HDRM，全新)
│   ├── Latch.SLDPRT
│   ├── Release_Actuator_Envelope.SLDPRT     功能包络，非飞行型号
│   ├── Preload_Spring.SLDPRT
│   ├── Status_Sensor_Envelope.SLDPRT        状态传感器包络
│   └── Mechanical_Stop.SLDPRT
│   输出 HDRM_FUNCTIONAL_DESIGN.md（明确 Engineering Candidate，非飞行）
│
├── [EXISTING - PARTIAL] 07_Gripper (URDF 运动学已有，制造级待 F3-E)
│   └── gripper_link + left + right（URDF mesh）
│
├── [TO_BUILD] 08_End_Effector (F3-E，三阶段)
│   ├── EE-V1 (接口级，比赛优先)
│   │   ├── Wrist_Flange.SLDPRT             腕法兰
│   │   ├── Camera_Mount.SLDPRT             相机座
│   │   ├── F_T_Sensor_Envelope.SLDPRT      力/力矩传感器包络
│   │   └── Capture_Center.SLDPRT           捕获中心
│   ├── EE-V2 (柔顺捕获，比赛优先)
│   │   ├── Compliant_Joint.SLDPRT          柔顺关节
│   │   ├── Passive_Damping.SLDPRT          被动阻尼
│   │   └── Guide_Cone_EE.SLDPRT            导向锥
│   └── EE-V3 (非合作目标，赛后)
│       ├── Grasp_Finger.SLDPRT ×N
│       └── Locking_Mechanism.SLDPRT
│
└── [EXISTING] 09_Solar_Array_Root ×2 (非 B601，但 F3-C 收拢干涉相关)
    └── 继承 V2_3；C5 超宽负结果保留
```

### 3.2 数量口径校正

用户提到"10 links 制造模型"与"10 carrier + J00-J09 + FK 验证已通过"。V2_3 B601 KINEMATIC_PROXY 实际为 base_link + link1..6 + gripper_link + gripper_left + gripper_right = **10 个运动学件**，与"10 links"口径一致。F3-P1 需在制造级阶段核对：
- base_link 是否单独制造（与适配器共享安装面）；
- gripper_left/right 是否归入 EE-V1 而非 Link；
- 6 个 J 关节壳体是否独立制造或与 link 一体化。

---

## 4. 交付物 2：零件 BOM 规划（规划态）

按"现有继承 / 待建 / 接口冻结"三类分。**质量为 URDF 真值，CAD 不覆盖**。

### 4.1 现有继承（V2_3 已冻结，F3 不重建）

| 类别 | 件数 | 来源 | F3 动作 |
|---|---|---|---|
| 主结构（环框/纵梁/甲板/外板） | 17 | `01_Primary_Structure` | 只读核对接口面 |
| B601 安装与载荷路径 | 8 | `02_B601_Mount_and_Load_Path` | 补螺栓圈/定位销参数 |
| B601 运动学代理 | 21 | `B601_KINEMATIC_PROXY` | 保持，作 FK 碰撞体 |
| B601 质量代理 | 11 | `B601_MASS_SURROGATE` | 保持，mass=EXCLUDED |
| 收拢支撑 | 5 | `04_ARM_STOW_SUPPORT` | 补 G07/G08 接触元件 |
| 帆板根部 | 18 | `05/06_Solar_Array_Root_*` | 保持，C5 负结果保留 |
| Master Skeleton | 1 | `00_Master_Skeleton_V2_2` | 增量参数写入属性 |

### 4.2 待建（F3-P1 授权后按子线推进）

| F3 子线 | 待建类别 | 件数估算 | 优先级 | 前置 |
|---|---|---|---|---|
| F3-A | B601_STOWED_HIFI（厂商 STEP 导入） | 1 装配 | P0 | 解决 35 MB STEP 导入失败史 |
| F3-A | Joint_Housing_Assembly ×6 | 6×(6..10) ≈ 36..60 | P1 | HIFI 几何 + 关节接口冻结 |
| F3-A | Output_Bearing_Structure ×6 | 6×(3..5) ≈ 18..30 | P1 | 轴承选型（待授权） |
| F3-A | Joint_Wiring ×6 | 6×(3..4) ≈ 18..24 | P2 | 关节壳体冻结 |
| F3-B | Link_Manufacturing ×N | N×(5..6)，N=6..10 | P2 | F3-A 关节冻结 |
| F3-C | G07/G08 接触元件 | 8..10 | P1 | 接触垫材料 + 预紧 + 发射载荷（HAG-A 影响物理分支） |
| F3-D | ARM_HDRM | 5 | P2 | F3-C 接触资格冻结 |
| F3-E | EE-V1 | 4 | P1 | F3-A 腕接口冻结 |
| F3-E | EE-V2 | 3 | P2 | EE-V1 完成 |
| F3-E | EE-V3 | 2..N | P3（赛后） | 不阻塞比赛 |

### 4.3 接口冻结件（每件输出 ICD）

| 接口 | 数量 | ICD 字段 | 当前状态 |
|---|---|---|---|
| 关节-连杆接口 | 6 | PCD / 螺栓规格 / 定位销 / 基准面 / 轴线 / 承载方向 | 未冻结 |
| 关节-基座接口 | 1 | 同上 + T_SM 数值轨裁决 | T_SM 双轨冲突 |
| 适配器-航天器接口 | 1 | 法兰面 / 螺栓圈 / 定位 | V2_3 已有几何，参数未冻结 |
| 鞍座-臂接触接口 | 3 | 接触垫材料 / 预紧 / 接触面积 / 摩擦系数 | CANDIDATE_HOLD |
| HDRM-鞍座接口 | 3 | 锁紧力 / 释放行程 / 状态传感 | 未冻结 |
| EE-腕接口 | 1 | 腕法兰 PCD / 螺栓 / 定位 | 未冻结 |
| EE-夹爪接口 | 1 | 夹爪开合行程 / 锁定 | URDF 运动学已有，制造级未冻结 |

---

## 5. 交付物 3：参数表（接口/材料/质量，规划态）

### 5.1 接口参数（拟冻结，待 HAG-F3-P1 授权）

```yaml
# 拟冻结参数表 — F3-P0 草案，未授权
joint_interface:
  PCD_mm: TBD                          # 螺栓分度圆
  bolt_spec: TBD                       # 例 M4×10
  positioning_pin: TBD                 # 例 Ø4 h7/h6
  datum_plane: TBD                     # 关节基准面
  axis: TBD                            # 旋转轴方向
  load_direction: TBD                  # 承载方向
  note: "每关节输出 JOINT_INTERFACE_CONTROL_DOCUMENT"

adapter_interface:
  footprint_mm: [160, 160, 12]         # 已冻结 arm_mount_v1.yaml
  boss_diameter_mm: 100                # 已冻结
  boss_height_mm: 15                   # 已冻结
  bolt_circle_PCD_mm: TBD              # 待冻结
  spacecraft_flange_datum: TBD         # 待冻结

stow_interface:
  saddle_contact_height_mm: [261.08, 214.92, 209.42]  # O13 v3 实测
  saddle_tower_height_mm: [147.93, 101.77, 96.27]      # O13 v3 实测
  contact_pad_material: TBD                            # 待 HAG-A + 实测
  preload_N: TBD                                      # 待发射载荷分析
  damping_coefficient: TBD                            # 待选型
```

### 5.2 材料候选（规划态，禁止作为工程真值）

| 部件 | 候选材料 | 候选来源 | 状态 |
|---|---|---|---|
| 关节主承力壳体 | Al 7075-T6 / Al 6061-T6 | 用户建议 + 航天成熟 | `DESIGN_PROPOSAL` |
| 连杆壳体 | CFRP / Al 蒙皮 | 用户建议 | `DESIGN_PROPOSAL` |
| 连杆端接 | Al 7075-T6 | 用户建议 | `DESIGN_PROPOSAL` |
| 接触垫 | TBD | 需 HAG-A 物理分支 | `UNKNOWN_BLOCKED` |
| 鞍座主体 | TBD | V2_3 已有几何，材料未定 | `UNKNOWN_BLOCKED` |
| HDRM 弹簧 | TBD | 需选型 | `UNKNOWN_BLOCKED` |
| 紧固件 | TBD | 需选型 | `UNKNOWN_BLOCKED` |

**禁止**：从视觉模型、案例或对话推断材料、板厚、紧固、载荷、刚度、强度、模态数值。

### 5.3 质量账本（双轨制）

```yaml
# 双轨原则：URDF = accepted dynamics truth；CAD = engineering estimate
URDF_mass_truth:                      # 来自 arm_b601_v1.yaml，禁止 CAD 覆盖
  total_arm_mass_kg: 4.4293
  gripper_mass_kg: 0.2665
  total_dynamics_mass_kg: 4.6956
  source: HYBRID_DevArm_inertial_set
  confidence: medium
  pending: physical_weighing_of_real_arm

CAD_mass_register:                    # 拟建，F3-P1 授权后
  schema: FREECAD_MASS_REGISTER.yaml  # 文件名沿用用户提议，但实际工具为 SolidWorks
  fields:
    component: <part_name>
    mass: <kg>                        # CAD 估算
    cg: [x, y, z]                     # m
    inertia: [Ixx, Iyy, Izz, Ixy, Ixz, Iyz]  # kg m^2
    source: <CAD_material_assignment>
    confidence: <low/medium/high>
  rule: "CAD_mass != URDF_mass; URDF wins for dynamics"
```

### 5.4 柔性接口模型（论文核心，F3 同步）

```yaml
# 拟建 B601_FLEX_MODEL.yaml — F3 同步动力学任务
flex_model:
  link_stiffness:
    link1..6: TBD                     # 需 FEA 或实验
  joint_stiffness:
    J1..J6: TBD                       # 需关节刚度测试或厂商数据
  base_compliance:
    T_SM_compliance: TBD              # 适配器+法兰刚度
  support_stiffness:
    saddle_contact_stiffness: TBD     # 需接触垫材料 + 预紧
  note: "与 sim_11 柔性耦合捕获任务可行域对接；当前 sim_11 帆板参数为占位"
```

---

## 6. 交付物 4：载荷路径图（发射/在轨/捕获，规划态）

### 6.1 发射段载荷路径（最严酷，F3-C 核心判据）

```
机械臂惯性载荷（收拢态，q_v3 + 25° clock）
        │
        ▼
   臂-鞍座接触面（3 站：Aft/Mid/Fwd）
        │   contact_pad_material = TBD（HAG-A 阻塞）
        │   preload = TBD
        │   damping = TBD
        ▼
   G07 鞍座塔（V2_3 已有 5 件）
        │   tower_height = 147.93 / 101.77 / 96.27 mm（O13 v3）
        ▼
   G08 腕支撑（待建）
        │   primary_stop = TBD
        │   secondary_stop = TBD
        │   preload_spring = TBD
        │   damping_element = TBD
        ▼
   航天器主结构（4 纵梁 + 5 环框 + 3 甲板）
        │   longerons 17×17 角点 ±101.65
        │   ring frames X -183..183
        ▼
   航天器-部署器接口（12U deployer，未定义）
        │
        ▼
   部署器-运载接口（未定义）
```

**关键 HOLD**：
- 接触垫材料/预紧/阻尼全部 TBD → CANDIDATE_HOLD；
- 发射载荷谱未定义 → 无法做强度/刚度校核；
- C5 翼板超宽 12 mm → 翼板本体不在 V2_3，但影响整星收拢包络；
- 收拢态 Z 上限 UNKNOWN → 高度合规无判据。

### 6.2 在轨展开段载荷路径

```
展开指令
        │
        ▼
   HDRM 释放（机械臂侧待建 F3-D；帆板侧已有）
        │   release_actuator = TBD
        │   preload_release = TBD
        ▼
   鞍座-臂分离（释放净空包络 V2_3 已有）
        │
        ▼
   关节驱动（B601 6R，q_v3 → DEPLOYED_NOMINAL）
        │   joint_torque = TBD（需厂商 QDD 数据）
        │   joint_stiffness = TBD（F3 同步）
        ▼
   基座反作用（sim_05 已建模 19.20° 扰动，但用的旧 2DOF 模型）
        │   ⚠ arm_b601_v1.yaml note: "sim_05 must re-derive with this model"
        ▼
   姿态控制系统（CTRL-01/02 已裁决，WAVE1_REPEAT）
```

### 6.3 捕获段载荷路径（论文 Paper 1 核心）

```
末端执行器接触目标（T 或 D）
        │
        ▼
   接触冲量（sim_06/sim_10/sim_11/sim_12 已建模）
        │   sim_11 v1.1: T_c=20 ms 名义 PROVISIONAL 待 B601 夹爪实测
        │   sim_12 Phase1: 策略集已裁决
        ▼
   末端-腕-臂载荷传递
        │   EE-V1 接口（待建 F3-E）
        │   joint_stiffness（待 F3 同步）
        ▼
   臂-基座耦合（sim_11 A1/A2 场景）
        │   base_compliance（待 F3 同步）
        ▼
   基座-帆板柔性耦合（sim_11 A2，|H_O|=3.678 N·m·s）
        │   ⚠ 帆板质量 0.348 kg 为 SSOT 占位（真实 2-5 kg/m²，差 5-10×）
        │   ⚠ 杨恒待办 3：真实参数下结论可能翻转
        ▼
   消旋推力器（sim_08：150 kg 碎片需推力器，|H_c|=3.65 N·m·s = 12× 轮组容量）
```

---

## 7. 交付物 5：F3 设计冻结方案

### 7.1 F3 阶段化授权建议

按用户建议的 F3-P0 → F3-P1 → F3-P2 → F3-P3 推进，**每阶段需独立人工 Gate**。

| 阶段 | 内容 | 建议授权名 | 前置 |
|---|---|---|---|
| F3-P0 | 机械架构冻结（本草案） | `HAG-F3-P0-PLANNING` | 本草案人工评审 |
| F3-P1 | 关节 + 连杆制造级 | `HAG-F3-P1-CAD_AUTHORING` | F3-P0 评审通过 + B601_STOWED_HIFI 导入方案验证 + T_SM 双轨裁决 |
| F3-P2 | 收拢机构 + HDRM | `HAG-F3-P2-CAD_AUTHORING` | F3-P1 关节接口冻结 + 接触垫材料选定（HAG-A 影响物理分支） |
| F3-P3 | 末端执行器 | `HAG-F3-P3-CAD_AUTHORING` | F3-P1 腕接口冻结 |

### 7.2 F3-P0 评审清单（本草案需人工确认）

- [ ] 状态校正（§0）是否接受？
- [ ] V2_3 SolidWorks 作为继续基线是否接受？（而非 FreeCAD）
- [ ] F3 5 子线优先级（F3-A → F3-B → F3-C → F3-D → F3-E）是否接受？
- [ ] B601_STOWED_HIFI 作为 F3-A 单点最大风险是否接受？
- [ ] T_SM 双轨冲突是否在 F3-P1 前裁决？
- [ ] C5 翼板超宽 12 mm 负结果是否继续保留？
- [ ] 接触垫材料是否需在 HAG-A 物理分支前预选？
- [ ] 质量/惯量双轨制（URDF 真值 / CAD 估算）是否接受？
- [ ] 柔性接口模型 B601_FLEX_MODEL.yaml 与 sim_11 对接是否在 F3 同步任务范围？

### 7.3 F3-P1 启动条件（硬性）

1. F3-P0 草案人工评审通过并签发 `HAG-F3-P0-PLANNING.yaml`；
2. B601_STOWED_HIFI 厂商 STEP 导入方案验证（35 MB，headless LoadFile4 失败史需绕过）；
3. `T_SM_TRACK_CONFLICT` 人工裁决（185.25 动力学 vs 198 显示）；
4. 关节选型数据：B601 QDD 电机/减速器/轴承规格（需联系厂商或实测）；
5. 接触垫材料候选（HAG-A 物理分支允许后）；
6. 与杨恒协作：帆板真实质量参数（待办 3，影响 F3 同步动力学）。

### 7.4 F3 同步动力学任务（每结构完成即更新）

| 同步项 | 触发 | 输出 | 状态 |
|---|---|---|---|
| 质量账本更新 | 每个零件/子装配冻结 | `FREECAD_MASS_REGISTER.yaml`（SolidWorks 实际） | 待 F3-P1 |
| 柔性接口模型 | 关节/连杆/基座/支撑任一冻结 | `B601_FLEX_MODEL.yaml` | 待 F3-P1 |
| 模态分析 Case 1 | 臂展开态结构冻结 | base fixed, first 10 modes | 待 F3-P1 |
| 模态分析 Case 2 | 全星装配冻结 | free-flyer + arm, first 10 modes | 待 F3-P2 |
| 与 sim_11 对拍 | 柔性模型建立 | sim_11 重跑（按 e15 REPEAT_ANCF_CERTIFICATION 要求） | 待 F3 同步 |

---

## 8. 阻塞清单与负结果保留

### 8.1 F3-P0 → F3-P1 的硬阻塞

| 阻塞 ID | 描述 | 影响子线 | 解除条件 |
|---|---|---|---|
| B-F3-01 | `V2_CAD_NOT_AUTHORIZED` | 全部 | F3-P0 评审 + `HAG-F3-P1-CAD_AUTHORING` |
| B-F3-02 | `B601_STOWED_HIFI` 未建 | F3-A/B/C/D/E | 35 MB STEP 导入方案验证 |
| B-F3-03 | `T_SM_TRACK_CONFLICT` 未裁决 | F3-A | 人工裁决 185.25 vs 198 |
| B-F3-04 | 关节选型数据缺失 | F3-A | 厂商 QDD/减速器/轴承数据 |
| B-F3-05 | `HAG-A ABSENT` | F3-C 接触资格物理分支 | HAG-A 签发或物理分支预选 |
| B-F3-06 | `STOW_Z_LIMIT_REFERENCE = UNKNOWN` | F3-C 高度合规 | 收拢态 Z 上限裁决 |
| B-F3-07 | 帆板质量占位 0.348 kg | F3 同步动力学 | 杨恒提供真实参数（待办 3） |
| B-F3-08 | B601 夹爪 T_c 实测 | F3-C 接触窗 | 硬件组实测（待办 2） |

### 8.2 必须保留的负结果（禁止隐藏/消解）

| 负结果 ID | 内容 | 来源 |
|---|---|---|
| NR-F3-01 | C5 收拢翼包超宽 238.3 > 226.3，超 12.0 mm | `CODEX_CONTINUATION_RECONCILIATION` §3 |
| NR-F3-02 | 翼根机构下限宽 302.3 mm（双侧 \|Y\|=151.15） | 同上 |
| NR-F3-03 | `STOW_VECTOR_STATUS = CANDIDATE_HOLD`，几何 PASS 但接触资格未定 | `O13_STOW_VECTOR_V3_REPORT` |
| NR-F3-04 | DEPLOYED_REFERENCE_Q0 的 10 处静态干涉 = `COLLISION_SAFETY_BLOCKED` | spacecraft-mechanical-design-agent §Mandatory truth corrections #6 |
| NR-F3-05 | e15 交叉求解最大差 5.64% > 5% 门槛 → `REPEAT_ANCF_CERTIFICATION` | CLAUDE.md 核心证据区 |
| NR-F3-06 | WAVE1_CTRL-01 L0 硬件有效稳定性 `NOT_EVALUATED_NO_ACTUATOR_DYNAMICS` | CLAUDE.md Wave1 段 |
| NR-F3-07 | WAVE1_CTRL-02 仅 7/16 在 R5 PROVISIONAL 下 `STABILIZED_WITHIN_WINDOW` | 同上 |

---

## 9. 允许与禁止声明（Required handoff）

```text
WORK_MODE: V2_ARCHITECTURE + CAD_ENTRY_REVIEW（planning only, no CAD authoring）

SOURCES_READ:
- CLAUDE.md
- .codex/AGENTS.md
- .codex/agents/spacecraft-mechanical-design-agent.md
- 10_research/knowledge_base/spacecraft_mechanical_design/README.md
- 20_engineering/config/geometry/arm_b601_v1.yaml
- 20_engineering/config/geometry/arm_mount_v1.yaml
- 20_engineering/stage1_spacecraft_layout/04_mass_inertia_budget/coordinate_frame_definition_v0.md
- 20_engineering/stage1_spacecraft_layout/04_mass_inertia_budget/mass_inertia_budget_v1.csv
- 20_engineering/cad/Space_Embodied_Robot_CAD_V2_3_NATIVE_INTEGRATION/baseline_freeze_manifest.yaml
- 20_engineering/cad/Space_Embodied_Robot_CAD_V2_3_NATIVE_INTEGRATION/V22_NATIVE01_PHASE1_REPORT.md
- 20_engineering/cad/Space_Embodied_Robot_CAD_V2_3_NATIVE_INTEGRATION/O13_STOW_VECTOR_V3_REPORT.md
- 20_engineering/cad/Space_Embodied_Robot_CAD_V2_3_NATIVE_INTEGRATION/CODEX_CONTINUATION_RECONCILIATION.md
- 20_engineering/cad/Space_Embodied_Robot_CAD_V2_3_NATIVE_INTEGRATION/phase0_completion_record.json
- 30_simulation/asm_00_interface_preflight/results/asm_00_gate_check.json
- V2_3 子目录结构：00_Master_Skeleton / 01_Primary_Structure / 02_B601_Mount_and_Load_Path / 03_B601_Three_Representations / 04_ARM_STOW_SUPPORT / 05_Solar_Array_Root_Left / 06_Solar_Array_Root_Right

EXACT_STATUS:
- V2_3_NATIVE_INTEGRATION: PHASE0_COMPLETE_BASELINE_FROZEN_AND_ISOLATED
- B601_KINEMATIC_PROXY: BUILT (21 files)
- B601_MASS_SURROGATE: BUILT (11 files)
- B601_STOWED_HIFI: CONFIRMED_NOT_CREATED (empty directory)
- asm_00: ASM00_AG0_BLOCKED_BY_INTERFACE, HAG-A ABSENT
- V2 CAD: NOT_AUTHORIZED (per AGENTS.md and spacecraft-mechanical-design-agent.md)
- FreeCAD F0-F2: NO EVIDENCE IN REPOSITORY (status correction accepted by user, Path A)

EVIDENCE_BOUND_FACTS:
- V2_3 contains 47 parts + 8 assemblies, all SolidWorks native, sha256-locked
- B601 total dynamics mass = 4.6956 kg (URDF HYBRID, confidence medium)
- T_SM nominal_frozen_v1 = [185.25,0,0] mm + R_y(90°), but display track = 198 mm (conflict)
- Stow vector v3 = clock 25°, q=[145.572,-168,-57,-41.143,-20.954,-3], clearance 15.56 mm
- 3 saddle stations: Aft/Mid/Fwd at z=261.08/214.92/209.42, tower 147.93/101.77/96.27
- C5 stowed package 238.3 mm > 226.3 mm available (12 mm overage, NEGATIVE_PRESERVED)
- Solar root mechanism lower bound width 302.3 mm (unresolvable)

DESIGN_PROPOSALS:
- F3 sub-line decomposition (F3-A..F3-E) mapped to V2_3 reality
- Manufacturing-grade structure tree (§3) with EXISTING/TO_BUILD tags
- BOM plan (§4) with 3 categories (inherit/build/freeze)
- Parameter table (§5) with frozen/TBD/proposed fields
- Load path diagrams (§6) for launch/on-orbit/capture
- F3-P0..F3-P3 authorization ladder (§7)

UNKNOWN_BLOCKERS:
- B601_STOWED_HIFI vendor STEP import (35 MB, headless failure history)
- T_SM track conflict (dynamics 185.25 vs display 198)
- Joint selection data (QDD motor / reducer / bearing specs)
- Contact pad material (HAG-A physics branch)
- Stowed Z upper limit (no compliance criterion)
- Solar panel real mass (Yang Heng TODO 3)
- B601 gripper T_c measurement (hardware team TODO 2)

NEGATIVE_RESULTS_PRESERVED:
- NR-F3-01: C5 stowed package overage 12 mm
- NR-F3-02: Solar root mechanism lower bound 302.3 mm
- NR-F3-03: STOW_VECTOR_STATUS CANDIDATE_HOLD
- NR-F3-04: DEPLOYED_REFERENCE_Q0 10 static interferences
- NR-F3-05: e15 REPEAT_ANCF_CERTIFICATION (5.64% > 5%)
- NR-F3-06: WAVE1 CTRL-01 L0 NOT_EVALUATED_NO_ACTUATOR_DYNAMICS
- NR-F3-07: WAVE1 CTRL-02 only 7/16 under R5 PROVISIONAL

FILES_CHANGED:
- 01_project/competition/F3_P0_mechanical_architecture_freeze_draft_20260804.md (NEW, this file)

FROZEN_BOUNDARY_CHECK: PASS
- No frozen files modified (V2_3, config/geometry, 30_simulation, 40_evidence, Gate JSON)
- No CAD files created or modified
- No URDF modified
- No Gate JSON modified

ALLOWED_CLAIMS:
- "F3-P0 architecture planning draft produced under Path A (status correction)"
- "V2_3 SolidWorks is the current CAD baseline; B601_STOWED_HIFI is the single largest gap"
- "F3 sub-lines mapped to V2_3 with EXISTING/PARTIAL/TO_BUILD classification"
- "All manufacturing-grade modeling actions remain PLANNED_NOT_AUTHORIZED"

PROHIBITED_CLAIMS:
- "F0-F2 FreeCAD PASS" (no evidence in repository)
- "FreeCAD manufacturing-grade pilot validated" (no FreeCAD files exist)
- "F3 CAD authorized" (only F3-P0 planning draft authorized under Path A)
- "B601_STOWED_HIFI built" (empty directory)
- "T_SM conflict resolved" (still open)
- "Contact pad material selected" (TBD, HAG-A blocked)
- "Stow vector qualified" (CANDIDATE_HOLD)
- "Mass/inertia from CAD = URDF truth" (URDF wins, CAD is estimate only)

NEXT_HUMAN_GATE:
- HAG-F3-P0-PLANNING: review and accept/reject this draft
- HAG-F3-P1-CAD_AUTHORING: authorize SolidWorks native CAD authoring for F3-A/B
- HAG-A: unblock asm_00 AG0 for F3-C contact qualification physics branch
- T_SM_TRACK_CONFLICT ruling: 185.25 (dynamics) vs 198 (display)
```

---

## 10. 下一步建议（不构成授权）

1. **请你评审本草案 §7.2 清单**，逐项 ✅/❌/改；
2. 若接受 F3-P0 草案，签发 `HAG-F3-P0-PLANNING.yaml`（建议放在 `01_project/competition/approvals/` 或 `10_research/on_orbit_assembly/approvals/` 并行目录）；
3. 同步裁决 `T_SM_TRACK_CONFLICT`（这是 F3-A 关节壳体建模的前置）；
4. 与杨恒推进帆板真实质量参数（待办 3，影响 F3 同步动力学与 sim_11 重跑）；
5. 与硬件组推进 B601 夹爪 T_c 实测（待办 2，影响 F3-C 接触窗）；
6. 若你确实有外部 F0-F2 FreeCAD 工作，请按路径 B 入库到 `20_engineering/cad/Space_Embodied_Robot_CAD_V3_0_FREECAD_F0_F2/`（建议命名），我核验后并入 F3-P0 草案升级版。

**本草案不启动任何建模动作。** F3-A..F3-E 全部子线在 `HAG-F3-P1-CAD_AUTHORING` 签发前保持 `PLANNED_NOT_AUTHORIZED`。

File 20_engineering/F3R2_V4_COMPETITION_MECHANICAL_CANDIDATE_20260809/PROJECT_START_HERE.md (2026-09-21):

# F3R2 V4 竞赛机械候选——阅读入口

本目录是 2026-08-09 建立的后继机械设计树。它不覆盖 F3R1，也不覆盖冻结的 F3R2 顶装；目标是把最后一轮可安全完成的机械设计做成可复核的中性 CAD，并把必须依赖 SolidWorks、实物或人审的门禁准确隔离。

当前机器裁定为：

`MFINAL_V4_NEUTRAL_MECHANICAL_DESIGN_BASIS_ESTABLISHED_NATIVE_RELEASE_HOLD`

这表示 Rev-B2 基座、翼根叉耳候选、G07/G08/Mid V2 支撑、HDRM 功能骨架、相机/线束包络以及夹爪三组分体已经形成中性几何和证据，但仍不是原生 SolidWorks 制造发布，也不是发射/飞行基线。

## 1. 本轮已经完成的内容

| 工作包 | 当前结果 | 不得外推的边界 |
|---|---|---|
| M-FINAL-01 基座 | Stage A 保持实测 4×M4 接口；Stage B Rev-B2 增加四个 R15 局部承载耳，4×M6@140×140 的净孔边由 6.7 mm 提升到 11.7 mm | 载荷桥实物孔系、紧固件预紧、MoS、试装、原生冷开仍待完成 |
| M-FINAL-02 翼根 | 左/右三腹板双剪叉耳、间隔片、挡块和护线套候选已建；Ø8 销/Ø8.4 孔、每侧 0.5 mm 耳侧间隙 | 尚未与真实翼板做原生布尔合并、配合、运动与干涉验证 |
| M-FINAL-03 支撑 | G07/G08/Mid V2 支撑体、载台与垫块已建；垫面分别锁定 z=261.5016/208.4929/212.9189 mm | 底脚孔位仍是工程候选，需从原生旧塔脚直接复测；预载需台架标定 |
| M-FINAL-04 HDRM | 权威链已统一为预载 +X、工作释放 -X、地面拆装 +Z、行程 6 mm；建立保守扫掠包络 | 未选电磁件、孔阵时钟角/定位销坐标、约束杯与物理释放试验，只有 skeleton |
| M-FINAL-05 相机/线束 | 40×34×26 相机包络和 OD9 静态线束扫掠已建；曲线最小弯曲半径 114.665 mm，超过 25 mm 要求 | `SERVICE_CAMERA=UNSELECTED`；无光学标定、连接器、活动线束扫掠 |
| M-FINAL-06 夹爪 | 58 个源实体分为 palm 10、left 24、right 24，并输出三组 FCStd/STL | 尚未 Save Bodies 成 SLDPRT、建立 SLDASM/棱柱配合/原生配置 |
| M-FINAL-07 位姿/路径 | 继承 5 个已有 q 向量并建立 V4 权限表 | 新硬件加入后必须重算；服务抓取等姿态不得由代理自行授权 |
| M-FINAL-08 放行/CM | 生成 BOM、构建回执、独立 OCP 回读验证与散列清单 | 原生工程图、全配置重建、Pack-and-Go、双进程冷开和人审仍为 HOLD |

## 2. 首选阅读顺序

1. `01_authority/MFINAL_CONTROL_BASELINE.yaml`：唯一控制边界。
2. `01_authority/MFINAL_AUTHORITY_MATRIX.csv`：八个工作包的 authority 与剩余门禁。
3. `10_validation/MFINAL_FREECAD_BUILD_RECEIPT.json`：全部几何、体积、质量、边界和输出路径。
4. `10_validation/MFINAL_INDEPENDENT_VALIDATION.json`：独立 STEP 回读与 10 组检查。
5. `09_bom/MFINAL_PROVISIONAL_BOM.csv`：23 行候选 BOM。
6. `08_poses_paths/MFINAL_POSE_AUTHORITY_REGISTER.csv`：姿态可用性与人审边界。
7. `11_release/MFINAL_GATE.json`：最终机器 Gate。

## 3. 重要工程数值

- 中性 CAD：26 FCStd、23 STEP、23 STL。
- Manifest 受控行：73；缺失 0；散列漂移 0。
- STEP 单零件回读：20/20 单实体、体积一致。
- 新增候选已知材料质量：1,293.360439 g；不含夹爪真实多材料质量、HDRM、相机、连接器和紧固件完整质量。
- 基座 Stage B Rev-B2：最大局部外廓 170 mm；M6 孔中心到局部边缘 15.0 mm，孔边净韧带 11.7 mm。
- 静态线束：OD 9 mm，Bezier 最小曲率半径 114.664713 mm。

## 4. 下一次原生执行条件

只有同时满足以下条件才进入 SolidWorks 写入轮：稳定可用物理内存至少 6 GiB；由当前用户人工启动 SolidWorks 2024 SP05；attach-only 预检通过；新 run-id 目录不存在；输入与模板散列完全匹配。原生构建与冷验证必须使用两个干净 SolidWorks 会话。

当前安全门位于 `99_tools/mfinal_solidworks_v4_attach.py`。它不会自行启动或关闭 SolidWorks，也不会把静态校验冒充冷重开验收。

## 5. 可接受的当前签署语义

可以签署：

`F3R2_V4_COMPETITION_NEUTRAL_MECHANICAL_DESIGN_BASIS`

不可以签署：

- `FINAL_NATIVE_CAD_BASELINE`
- `MANUFACTURING_RELEASED_BASELINE`
- `LAUNCH_OR_FLIGHT_QUALIFIED_BASELINE`
- `FULLY_AUTHORIZED_SERVICE_AND_GRASP_TRAJECTORY`

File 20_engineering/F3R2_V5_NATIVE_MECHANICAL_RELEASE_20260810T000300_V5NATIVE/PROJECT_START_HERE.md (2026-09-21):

# F3R2 V5 native mechanical release

Run ID: `20260810T000300_V5NATIVE`

Current status: `LOOP1_NATIVE_ASSEMBLY_IN_PROGRESS_TOOLING_HOLD`.

2026-08-10 continuation: offline digital-thread six-file seed PASS; latest
Loop1B/1C/1D/1E/2/3 execution scripts are staged under `99_tools/`; resume
queue is in `00_authority/V5_RESUME_EXECUTION_QUEUE.md`.

This tree is a V5 successor. V4 and all frozen baselines remain read-only. No final mechanical-baseline claim is authorized until all three engineering loops, Pack-and-Go, new-session cold reopen, drawings/BOM, review book and final Gate pass.

Verified current boundary:

- G0 smoke/cold-reopen gate: PASS (historical receipt retained).
- Session: requalified to blank SolidWorks 2024 PID 87516 at 2026-08-10T13:43Z (`00_authority/V5_SESSION_REQUALIFICATION.json`); session is reserved for the orchestrator, attach-only.
- Memory gate: available RAM still below the mandatory 6 GiB; execution proceeds under signed USER_OVERRIDE (`00_authority/V5_MEMORY_GATE_USER_OVERRIDE.json`, scope ALL_V5_NATIVE_EXECUTION_AND_G0) with actual ~1.3-4.0 GiB post-override samples recorded in receipts — USER_OVERRIDE, not PASS.
- Protected PRE hashes: 6/6 unchanged.
- Neutral native import: 20/20 parts PASS.
- Loop 1A: Rev-B2 adapter plus G07/G08/Mid native subassemblies independently cold-reopened PASS.
- Solar array candidate: PASS — 6 simplified placeholder panels plus `L_SOLAR_ARRAY.SLDASM`/`R_SOLAR_ARRAY.SLDASM`, 7 configurations each, cold-verified (`13_validation/V5_SOLAR_ARRAY_NATIVE_RECEIPT_20260810T135905.775293Z.json`; 5 earlier FAIL receipts retained as history). Candidate placeholder only; no final-baseline or flight claim.
- LOOP-SOLAR-B solar completion: PASS — 42/42 panel poses applied and cold-verified non-resume (7 configs x 3 panels x 2 sides, closing the F-3 evidence-chain gap), 8 placeholder parts (SOLAR_HARNESS_EXIT_L/R, SOLAR_STOW_PAD_L/R, SOLAR_DEPLOY_STOP_L/R_H1/H2), per-state register `04_configurations/V5_SOLAR_STATE_REGISTER.csv` (collision/camera/clearance columns PENDING_LOOP2), FAIL configs CANDIDATE-registered with mapping note to authoritative L_FAIL(0/90)/R_FAIL(90/0) (`13_validation/V5_SOLAR_ARRAY_COMPLETION_RECEIPT_20260811T113120.766168Z.json`, verdict `V5_SOLAR_ARRAY_COMPLETION_PASS`, 2026-08-11T11:31Z). Candidate placeholder only; no final-baseline or flight claim.
- Loop 1B: PASS — left/right true-hinge assemblies with six configurations built and cold-reopened (`13_validation/V5_LOOP1B_WING_ROOT_RECEIPT.json`, verdict `V5_LOOP1B_DUAL_WING_ROOT_NATIVE_CLOSURE_PASS`, 2026-08-10T22:57Z; `02_native_subassemblies/LEFT_WING_ROOT_TRUE_HINGE.SLDASM`/`RIGHT_WING_ROOT_TRUE_HINGE.SLDASM`; `14_release/V5_LOOP1B_WING_ROOT_MANIFEST_SHA256.txt`; 15 historical FAIL receipts retained as history).
- Loop 1C0: three physical gripper parts (PALM/LEFT_FINGER/RIGHT_FINGER) native split PASS (`13_validation/V5_LOOP1C0_GRIPPER_NATIVE_PART_RECEIPT.json` + 3 checkpoints).
- Loop 1C1: HOLD — `BLOCKED_AT_INTERFERENCE_GATE_PENDING_CONTRACT_DECISION`. 23 fail-closed receipts; all assembly-side defects fixed and live-proven (guide mates, limit-mate plain-create+ModifyDefinition recipe, per-config SetSystemValue3 drive, mate ledger dynamic dispatch); final blocker is donor-inherited geometry: donor part `B51_REF_gripper_detail_LINKLOCAL.SLDPRT` contains 81 internal positive-volume interferences bit-identical to V5 CLOSED-state rows (probe evidence `99_tools/probe_logs/`, esp. INTERFERENCE_BODIES logs). Decision options in `99_tools/V5_LOOP1C1_FIX_PROPOSAL_20260810.md` §5: A contract amendment accepting the donor-inherited fingerprint table (recommended) / B part rework cascading into frozen input hashes / C ungated accept (not recommended).
- Loop 1D: PASS — HDRM six-state functional envelope, service-camera interface hold (SERVICE_CAMERA stays UNSELECTED) and B601 OD9 static harness interface (`13_validation/V5_LOOP1D_HDRM_CAMERA_HARNESS_RECEIPT.json`, verdict `V5_LOOP1D_HDRM_CAMERA_HARNESS_NATIVE_FUNCTIONAL_INTERFACE_PASS`, 2026-08-11T10:23Z; `14_release/V5_LOOP1D_HDRM_CAMERA_HARNESS_MANIFEST_SHA256.txt`).
- Loop 1E / Loop 2 / Loop 3 and final Gate: BLOCKED upstream — Loop1E `V5_LOOP1E_STATIC_PENDING_UPSTREAM` (sole missing receipt = GRIPPER from Loop1C1; other 9 v5_components receipt-OK), Loop2 `V5_LOOP2_SCRIPT_READY_LOOP1E_INPUTS_PENDING`, Loop3 `V5_LOOP3_STATIC_HOLD`; single unblock key is the Loop1C1 contract decision (A/B/C).

The authoritative requirement-by-requirement status is `13_validation/V5_COMPLETION_EVIDENCE_MATRIX.csv`. A PASS row requires direct artifact/receipt evidence; absence of evidence remains PENDING or HOLD.

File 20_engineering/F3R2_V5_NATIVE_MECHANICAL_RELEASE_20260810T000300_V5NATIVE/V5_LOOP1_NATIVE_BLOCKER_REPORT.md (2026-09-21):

# V5 Loop1 原生主线阻塞报告

更新：2026-08-10（本地）

## 已固化成果

- Loop1D 9 个功能零件（HDRM 5、相机 2、线束 2）已生成并冷重开 PASS：
  `01_native_parts/loop1d_functional/`
- 数字线程六文件、原型紧固件注册表、BOM 种子、41 文件完整性审计均为 PASS。
- Loop1B/1C0/1C1/1D/1E/2/3 静态审计通过或按依赖顺序 PENDING。

## 阻塞 1：Loop1B 翼根真铰链装配

- 现象：`HINGE_GROUP_KINEMATIC_DRIFT`；PANEL/LUG 无法作为同一刚体绕 X 铰链轴到达期望位姿。
- 已试两次局部修正（锁合前对齐、双组件同体位姿驱动），均被 SolidWorks 配合求解覆盖。
- 证据：`13_validation/V5_LOOP1B_FAIL_20260810T080311.217255Z.json`、`...080512.337239Z.json`、`...080738.338581Z.json`。
- 所需方案：角度配合或嵌套子装配驱动（机械架构级脚本重写，需授权）。

## 阻塞 2：Loop1C0 夹爪三零件拆分

- 现象：`SOURCE_LOCAL_LABEL_FAIL`；donor SLDPRT 的 57 个实体名为 “Open CASCADE STEP translator...”，不是 B51 标签。
- 受保护 donor 不可改名，需按 B-rep 指纹映射到既有 57 标签（脚本改造，需授权）。
- 证据：`13_validation/V5_LOOP1C0_FAIL_20260810T...json`（本轮失败回执）。

## 阻塞 3：Loop1D HDRM/相机/线束装配

- 现象：实例名只读、状态常量错误已修复；但 HDRM 单装配进入 SolidWorks 重建死循环（8 分钟未落盘、CPU 满载、COM 无响应）。
- 证据：`13_validation/V5_LOOP1D_FAIL_20260810T083258.443061Z.json` 及中断记录。
- 所需动作：交互式 SolidWorks 会话逐配置调试，或改为“每配置独立位姿+配合抑制”的不同实现（需授权）。

## 需要用户决策

1. 是否授权 Loop1B 角度配合/嵌套子装配重写。
2. 是否授权 Loop1C0 B-rep 指纹映射改造。
3. 是否提供可交互 SolidWorks 会话继续 Loop1D 专项调试，或接受当前 9 零件+离线证据的阶段冻结。

## 非声明

- 没有最终原生基线、工程图、BOM、Pack-and-Go、双会话冷重开或最终门禁证据。
- 未触碰受保护资产（URDF/F3R1/F3R2/V2_2/V4）。

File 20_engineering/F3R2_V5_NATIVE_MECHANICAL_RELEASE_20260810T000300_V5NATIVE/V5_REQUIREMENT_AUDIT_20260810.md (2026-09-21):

# F3R2 V5 机械主线要求审计（2026-08-10）

当前机器裁决：`TOOLING_HOLD`（可用内存 3.02 GiB，SolidWorks 2024 SP05 在运行）。

| 要求段 | 状态 | 证据 / 说明 |
|---|---:|---|
| 1 真值保护 | PASS | URDF/质量预算/F3R1/F3R2/V2_2 哈希 6/6 未漂移 |
| 2 G0 门禁 | HOLD | 内存 3.02 GiB < 6 GiB；不伪造 PASS |
| 3 V5 唯一树 | PASS | `F3R2_V5_NATIVE_MECHANICAL_RELEASE_20260810T000300_V5NATIVE` |
| 4 M-FINAL-01 基座 | 部分 PASS | Rev-B2 零件与子装配原生 PASS；顶装复测待 Loop2 |
| 5 M-FINAL-02 翼根 | 部分 PASS | donor 零件/U 耳/保持件 PASS；真铰链六配置待 Loop1B |
| 6 M-FINAL-03 G07/G08/Mid | 部分 PASS | 原生子装配 PASS；顶装面距/干涉待 Loop2 |
| 7 M-FINAL-04 HDRM | PENDING | 六状态原生功能样机待 Loop1D |
| 8 M-FINAL-05 相机/线束 | PENDING | 相机保持 UNSELECTED/HOLD；线束静态包络已导入 |
| 9 M-FINAL-06 夹爪 | PENDING | 57 实体三零件与棱柱装配待 Loop1C0/1C1 |
| 10 姿态 Authority | HOLD | 三个运行时输入保留；服务姿态需人工授权 |
| 11 原生连续路径 | PENDING | 待 Loop1E 顶装后 Loop2 |
| 12 紧固件 | PASS（原型级） | `V5_FASTENER_REGISTER.csv` 8 行；`FORMAL_LAUNCH_FASTENER_MOS=HOLD` |
| 13 质量/质心/惯量 | 部分 PASS | 16 项来源分级种子已建；原生测量待 Loop3 |
| 14 工程图/BOM | 部分 PASS | 原生 BOM 种子 49 行已建（`08_bom/V5_NATIVE_BOM_SEED.csv`）；工程图/正式 BOM 待 Loop3 |
| 15 数字线程 | PASS | 六文件 Loop3 静态审计 PASS |
| 16 Pack-and-Go | PENDING | 待顶装后执行 |
| 17 双会话冷重开 | PENDING | 旧 Session B 已失效；新会话重认证机制就绪 |
| 18 人审图册 | PENDING | 22 张 RAW/ANNOTATED 待截图 |
| 19 Loop 工程 | 进行中 | Loop1 静态就绪；Loop2/3 按依赖 PENDING |
| 20 最终 Gate | PENDING | 未达任何最终称谓 |
| 21 冻结规则 | 待生效 | 最终 Gate 通过后 `FREE_MECHANICAL_CAD_AUTHORING=PROHIBITED` |

## 唯一阻塞

可用物理内存不足 6 GiB。原生写入只有在稳定达标后开始；当前不伪造 G0/native PASS。

## 下一动作（内存达标后自动执行）

`G0 smoke + Session B 冷重开 → V5_SESSION_REQUALIFY → Loop1B → Loop1C0/1C1 → Loop1D → Loop1E → Loop2 → Loop3 → FINAL GATE`

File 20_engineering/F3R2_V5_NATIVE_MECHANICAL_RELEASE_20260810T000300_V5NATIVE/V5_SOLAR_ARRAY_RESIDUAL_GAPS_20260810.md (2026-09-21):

# V5_SOLAR_ARRAY_RESIDUAL_GAPS — 太阳翼残余缺口登记（2026-08-10）

性质：只读分析报告。本报告不断言任何新证据、不修改任何受保护文件、不触碰 SolidWorks 会话（PID 87516 保留给编排器）。所有结论来自对现有文本/JSON/目录清单的静态比对。

## 0. 方法与输入

比对对象（as-required）：

- `00_authority/SOLAR_ARRAY_INTERFACE_REQUIREMENTS.md`（下称 REQU，CANDIDATE_INTERFACE_FROZEN_FOR_NATIVE_BUILD）
- `00_authority/SOLAR_ARRAY_CANDIDATE_BUILD_PLAN.md`（下称 PLAN）
- 上级指令要求的 per-state 记录、OD9 出口、收拢登记、deployed stop、质量占位、原生 B-rep 间隙复验六类闭合项

比对基准（as-built）：

- `13_validation/V5_SOLAR_ARRAY_NATIVE_RECEIPT_20260810T135905.775293Z.json`（下称 RCPT，verdict=`V5_SOLAR_ARRAY_CANDIDATE_NATIVE_PANELS_AND_SIDE_ASMS_PASS`，RCPT:318）
- `99_tools/F3R2_V5_NATIVE_SOLAR_ARRAY_BUILD.py`（下称 SCRIPT）
- `01_native_parts/solar_array/`（仅 6 个 SLDPRT）、`02_native_subassemblies/`（L/R_SOLAR_ARRAY.SLDASM）目录清单
- `04_configurations/`、`05_clearance/`、`06_mass_properties/`、`08_bom/`、`09_digital_thread/` 文本内容
- `13_validation/V5_SOLAR_ARRAY_FAIL_20260810T1345..1350*.json`（5 份 FAIL 回执）

## 1. 状态总览

| 状态 | 计数 | 条目 |
|---|---:|---|
| DONE | 5 | R1, R5, R13, R14, R15 |
| PARTIAL | 4 | R2, R3, R7, R16 |
| MISSING | 7 | R4, R6, R8, R9, R10, R11, R12 |
| DEFERRED（设计性推迟，已登记） | 1 | R4 的铰链配合部分见 §3 F-1 |

关键结论：RCPT 只证明“6 块简化板 + 2 个含 7 配置名集的侧装配存在且可冷重开”。配置内部位姿、铰链、止挡、收拢/线束接口、质量占位、数字线程注册、原生间隙证据全部未闭合。

## 2. 要求逐条对照表

| # | 要求（来源） | as-built 证据 | 状态 | 闭合责任 |
|---|---|---|---|---|
| R1 | 6 panel 简化板、禁止太阳电池片（REQU §2.1 行67；PLAN §1 行28） | 6 个 SLDPRT 冷开 0 错 0 警、单实体、box 6.0×56.67×227.0（RCPT:21-42 等；SCRIPT:42-44）；`SOLAR_CELL_DETAIL=PROHIBITED`（SCRIPT:113）；non_claims 含 `NO_SOLAR_CELL_DETAIL`（RCPT:289-294） | DONE | — |
| R2 | 每 hinge 明确轴向量+轴点；禁止双实体伪造运动（REQU §2.2 行68） | 铰链轴仅以文本自定义属性存在：`HINGE_AXIS=X@ROOT_Y=±143.15mm`（SCRIPT:115）；无任何铰链配合/轴特征——SCRIPT 设计注记明确推迟（SCRIPT:8-9 "kinematic hinge mates are a separate later step"）；面板间铰链（L1-L2/L2-L3）轴完全未定义 | PARTIAL | 太阳翼收口脚本（建议新 `F3R2_V5_NATIVE_SOLAR_ARRAY_COMPLETION_ATTACH_ONLY.py`，下称 LOOP-SOLAR-B），依赖 Loop1B 角度配合方案先行 |
| R3 | 同一物理 panel 绕真实 hinge 运动、配置间单实体（REQU §2.5 行71；PLAN §3 行52） | 单实体满足：每配置对同一组件 `SetTransformAndSolve3`（SCRIPT:245-265），无 STOWED/DEPLOYED 双实体；但运动由每配置静态变换给定，非绕铰链约束解算 | PARTIAL | LOOP-SOLAR-B（铰链配合化后重出回执） |
| R4 | 7 个太阳态 per-state 记录：panel angle / hinge state / collision state / camera visibility / arm clearance（上级指令） | 7 配置名集双侧冷验通过（RCPT:261-269, 277-285；SCRIPT:50-58, 284-286）；但 RCPT 无任何 per-config 位姿/角度行——两侧装配均 `resumed_from_existing`（RCPT:239, 249），跳过了 SCRIPT:265 的 `configurations` 记录行；hinge state 不存在（无铰链）；collision/camera/clearance 记录不存在：`05_clearance/` 为空目录，`04_configurations/` 仅有机械臂姿态登记（`V5_POSE_AUTHORITY_REGISTER.csv` 行1-10，无太阳态） | MISSING（名集 DONE / 记录 MISSING） | per-state 记录由 LOOP-SOLAR-B 生成（建议落 `04_configurations/V5_SOLAR_STATE_REGISTER.csv` + 新回执）；collision/camera/clearance 字段由 Loop2 填充 |
| R5 | 中间展开角不升格、保持 CANDIDATE（REQU §1 行40-41, 48；PLAN §5 行65） | 无任何升格记录；RCPT non_claims 完整（RCPT:289-294）；人审签发未见，符合保持要求 | DONE（合规保持） | human 签发前持续保持 |
| R6 | OD9 线束出口每侧 ≥1 个 + service loop 接口，最小弯曲半径 ≥25 mm（REQU §2.6 行72；PLAN §1 行23） | `01_native_parts/solar_array/` 仅 6 个 panel SLDPRT，无 `SOLAR_HARNESS_EXIT.SLDPRT`；Loop1D 已有 `B601_OD9_HARNESS_CLAMP` / `B601_HARNESS_SERVICE_LOOP_ENVELOPE` 但属机械臂侧（`00_authority/V5_LOOP1D_SCRIPT_CONTINUATION.json` 行40-50），非太阳翼出口 | MISSING | LOOP-SOLAR-B 建件+接口登记；弯曲半径原生 B-rep 验证入 Loop2 |
| R7 | FAIL/中间构型与权威映射一致（REQU §1 行39-46；PLAN §3 行44-50） | STOWED=0/0/0、DEPLOYED_NOMINAL=90/90/90、BOTH_FAIL=0/0/0 与权威端点一致（SCRIPT:197-206）；但 `SOLAR_LEFT_FAIL={1:deployed,2,3:stowed}`、`SOLAR_RIGHT_FAIL={1,2,3:deployed}` 与权威 `L_FAIL(0/90)`/`R_FAIL(90/0)` 不一致，且 `config_pose_map(side)` 忽略 side 参数、左右两装配位姿表完全相同（SCRIPT:197-206）——侧装配内 FAIL 构型编码的是未签发中间角候选而非权威 0° 失效语义 | PARTIAL（语义偏差，未升格故无权威违例） | LOOP-SOLAR-B 修正位姿表或显式登记为 CANDIDATE 中间角，待 human 签发 |
| R8 | 收拢接口 vs G07/G08/Mid 分开登记（REQU §2.3 行69；PLAN §1 行22 `SOLAR_STOW_PAD`） | 无 stow pad 零件；无任何收拢接触/预载登记记录；`04_configurations/` 无对应条目 | MISSING | LOOP-SOLAR-B 建 stow pad 占位 + Loop1E 顶装上下文内登记（接触语义按 REQU 保持分离） |
| R9 | 每 hinge 一个 deployed stop，角度与接触面需原生 B-rep 证据（REQU §2.4 行70；PLAN §1 行19-21） | 无 `SOLAR_DEPLOY_STOP.SLDPRT`、无 `ROOT_HINGE_ASSEMBLY`/`INTER_PANEL_HINGE` 装配件（目录清单实证）；无角度配合/限位配合；Loop1B 翼根真铰链本身未完成（`V5_LOOP1_NATIVE_BLOCKER_REPORT.md` 行12-17，`HINGE_GROUP_KINEMATIC_DRIFT`，12 份 FAIL 回执） | MISSING | Loop1B（翼根铰链/止挡 B-rep 前提）→ LOOP-SOLAR-B（止挡件+角度配合）→ Loop2 出 B-rep 接触证据 |
| R10 | 每 panel external mass placeholder，来源 ESTIMATED，不并入 L0 URDF/航天器质量真值（REQU §2.7 行73 + 上级指令） | panel 仅有文本属性 `MASS_SOURCE=EXTERNAL_MECHANICAL_ONLY`（SCRIPT:114）；`06_mass_properties/V5_EXTERNAL_MECHANICAL_MASS_SEED.csv` 16 行无任何 solar 行（行2-17）；`V5_MASS_BOUNDARY.yaml` `required_items` 16 项无 solar（行11）；`08_bom/` 两个 BOM 种子均无 SOLAR 行（全文检索无命中） | MISSING | 静态数据步：质量种子追加 6 行 ESTIMATED 占位（可即刻做，不需 SolidWorks）；Loop3 原生测量后 ESTIMATED→MEASURED_CAD 替换，全程不并入 L0 |
| R11 | arm↔solar / camera↔solar / harness↔solar 原生 B-rep 间隙复验；禁 bbox 终证；empty/Infinity/skipped fail-closed（REQU §4 行92-102 + 上级指令） | `05_clearance/` 空目录；`09_digital_thread/V5_COLLISION_ASSET_MANIFEST.csv` 仅含历史 L2_MESH `WING_L/R_DEPLOYED` STL（行57-58，源自 F3R2 冻结树），无 V5 原生太阳翼资产；AM 规则要求 `native_revalidation: REQUIRED_AFTER_V5_TOP_ASSEMBLY`（`V5_ACTION_MASK_RULES.yaml` 行71） | MISSING | Loop2（依赖 Loop1E 顶装 + Loop1D 相机/线束包络完成）；fail-closed 规则沿用 REQU §4 行102 |
| R12 | 数字线程注册（frame mapping / link-component mapping / collision manifest / BOM） | `V5_FRAME_MAPPING.yaml` `native_component_frames`（行85-93）无 SOLAR_PANEL/L_R_SOLAR_ARRAY；`V5_LINK_COMPONENT_MAPPING.csv` 仅 Loop1B 翼板件（行39, 47）；collision manifest 见 R11；BOM 见 R10 | MISSING | `F3R2_V5_DIGITAL_THREAD_SEED_GENERATOR.py` 修订增补 + Loop2 以原生资产重注册 |
| R13 | UNKNOWN/HOLD 机构参数不得填值（REQU §3 行79-88） | SCRIPT 仅写身份类属性（SCRIPT:109-116），未填 hinge_pin_diameter/spring/stop/cable_bend_radius 等任何冻结项 | DONE（合规保持） | 持续保持；LOOP-SOLAR-B 不得越界填值 |
| R14 | 非声明边界：非部署器合格/非飞行资质/不改 L0 真值（REQU §8 行141-142；PLAN §6） | RCPT non_claims：`NOT_FINAL_NATIVE_BASELINE/NOT_FLIGHT_READY/NO_SOLAR_CELL_DETAIL/NO_L0_MASS_OVERRIDE`（RCPT:289-294）；受保护资产零触碰 | DONE（合规保持） | — |
| R15 | 5 项禁止称谓不断言 | 全部证据与报告中未出现禁止称谓的达成断言 | DONE | — |
| R16 | 7 配置族存在性（REQU §1 行37-46；PLAN §3） | 双侧装配冷验配置名集 = 7（RCPT:261-269, 277-285）；但见 F-3 证据链缺口：配置内位姿变换无 PASS 回执 | PARTIAL | LOOP-SOLAR-B 全量重建验证（非 resume）出新回执 |

## 3. 额外发现（非逐条要求，但影响收口）

- F-1 设计性推迟已登记：铰链配合被 SCRIPT 明确推迟以规避 Loop1D 抑制/重建挂死（SCRIPT:8-9）。此为已声明的 DEFERRED，不是遗漏；闭合入口是 LOOP-SOLAR-B，且应复用 Loop1B 待授权的角度配合/嵌套子装配方案（`V5_LOOP1_NATIVE_BLOCKER_REPORT.md` 行17）。
- F-2 几何偏差未登记：PLAN §2 候选为每板 ~66.7×200×6 mm（行34）、面板内缘 y=±113.15 mm（行9，F3R2 实测）；as-built 为 56.67×227×6 mm（SCRIPT:42-44；RCPT:33-37）、deployed 起始 y=±143.15、stowed 折叠点 y=±116.15（SCRIPT:45-48, 131-140）。外展终点 143.15+3×56.67=313.16 mm 与 donor 实测 313.15 mm 吻合（PLAN 行10），但内段 113.15→143.15 的 30 mm 未被 panel 覆盖、单板划分与计划值不一致。双方均为 CANDIDATE_PLACEHOLDER（PLAN §2 行32），无违例，但偏差未在任何文件中登记。
- F-3 证据链缺口：5 份 FAIL 回执（13:45:45Z→13:50:18Z）均失败于 `config transform failed SOLAR_DEPLOY_STAGE1 panel 1`；两侧 SLDASM 落盘时间 13:57Z，无对应回执；PASS 回执（13:59:05Z）全部 `resumed_from_existing`，冷验仅核对配置名集（SCRIPT:284-286），不重验配置内位姿。结论：现有证据不能证明 7 配置内面板位姿变换曾被成功执行并验证——必须由 LOOP-SOLAR-B 以非 resume 全量路径出新回执闭合。
- F-4 命名不一致：REQU §1 用 `SOLAR_DEPLOYING_STAGE1/2`（行40-41），PLAN/as-built 用 `SOLAR_DEPLOY_STAGE1/2`（PLAN 行45-46；SCRIPT:51-52）。建议统一，避免登记键分裂。
- F-5 PLAN §1 零件族缺口：11 类目标件中仅 6 panel 已建；`ROOT_HINGE_ASSEMBLY.SLDASM`、`INTER_PANEL_HINGE.SLDASM×2/侧`、`SOLAR_DEPLOY_STOP.SLDPRT×2/侧`、`SOLAR_STOW_PAD.SLDPRT`、`SOLAR_HARNESS_EXIT.SLDPRT`（PLAN 行19-23）全部未建。

## 4. 拟议要求文件修订（仅提案，不改动受保护文件）

- P-1（PLAN §2）：将候选几何更新为 as-built 56.67×227×6 mm、deployed 内缘 y=±143.15、stowed 折叠点 y=±116.15，或恢复计划值并由 LOOP-SOLAR-B 重建；二选一，但须登记偏差来源。
- P-2（PLAN §1）：把零件族拆为 Phase-A（6 panel + 2 侧装配，变换式，已执行）与 Phase-B（铰链/止挡/stow pad/线束出口，LOOP-SOLAR-B），使计划与执行历史一致。
- P-3（REQU §1）：为三板翼定义 `SOLAR_LEFT_FAIL`/`SOLAR_RIGHT_FAIL` 的逐板角度语义（现权威 L_FAIL/R_FAIL 是单板 0/90 语义），并明确 `SOLAR_DEPLOY(ING)_STAGE*` 命名。
- P-4（REQU §2 新增）：定义 per-state 记录 schema（state, panel_angle_deg[3], hinge_state[3], collision_state, camera_visibility, arm_clearance_mm, evidence_ref, owner）与存放位置（建议 `04_configurations/V5_SOLAR_STATE_REGISTER.csv` + per-state 回执）。
- P-5（`V5_MASS_BOUNDARY.yaml`）：`required_items` 增补 `solar_panel_L1..R3`（或单列太阳翼 annex），来源等级 ESTIMATED 起步，Loop3 原生测量后升级 MEASURED_CAD。

## 5. 建议闭合顺序（与 Loop1B/Loop1C1/Loop1D → Loop1E → Loop2 → Loop3 依赖序一致）

1. 静态步（无需 SolidWorks，可即刻）：撰写 LOOP-SOLAR-B 脚本 + 质量种子/数字线程种子增补（R10 的 ESTIMATED 占位、R12 注册、P-4 记录 schema），静态审计 + `python -m py_compile`。
2. Loop1B 完成翼根真铰链装配（当前 `HINGE_GROUP_KINEMATIC_DRIFT` 阻塞，需先授权角度配合/嵌套子装配重写）——产出太阳翼 root hinge 轴/销/止挡的原生 B-rep 前提。
3. Loop1C1 完成夹爪棱柱配合（最新阻塞 `LIMIT_MATE_ADD_FAIL`，`V5_LOOP1C1_FAIL_20260810T151856.525979Z.json`）；Loop1D 完成 HDRM/相机/线束装配——产出 camera↔solar、harness↔solar 间隙对的另一端几何。
4. 执行 LOOP-SOLAR-B：铰链/止挡/stow pad/线束出口建件，铰链配合 + 每 hinge 一个 deployed stop 角度配合，FAIL 构型位姿表修正或 CANDIDATE 登记，per-state 记录生成，非 resume 全量验证出新回执（闭合 R2/R3/R4/R6/R7/R8/R9 几何段、F-3）。
5. Loop1E 顶装：L/R_SOLAR_ARRAY 经 root hinge 接入翼根/舱体；收拢接口 vs G07/G08/Mid 在顶装上下文登记（R8 登记段）。
6. Loop2：原生 B-rep 间隙复验 arm↔solar、camera↔solar、harness↔solar（含 REQU §4 的 HDRM residual↔solar），per-state 记录的 collision/camera/clearance 字段填充；empty/Infinity/skipped 一律 fail-closed（R4 字段段、R6 验证段、R9 证据段、R11）。
7. Loop3：质量 ESTIMATED→MEASURED_CAD 替换、BOM/工程图太阳翼行、Pack-and-Go 纳管、release evidence（R10 升级段、R12 终验）。

## 6. 非声明

本报告不是部署器合规、发射包络、展开动力学、可靠性或飞行资质结论；不改变 L0 动力学真值；不构成任何最终基线或 release 证据；未修改/删除任何既有回执或受保护基线；未附加到 SolidWorks 会话。

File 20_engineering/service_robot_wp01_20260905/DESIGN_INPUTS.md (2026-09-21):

# WP01：服务星与 B601 联合设计输入

日期：2026-09-05。工作包：`SERVICE_ROBOT_WP01_20260905`；首候选：`WP01_ROOF_EXTERNAL_R1`；主参数源：`design_parameters.json`。设计级别：可修改的总体布局候选；本轮用户已明确要求开始进一步机械设计。附件中的旧只读审计任务作为来源记录，其停工措辞不替代本轮请求。本文不给历史设计或本轮候选附加制造、试验或飞行合格结论。

## 一页输入表

| 项目 | 本轮确定的输入 / 设计取值方式 | 来源类别与下一步补齐 |
|---|---|---|
| 首版产品 | 任务优先的 12U 衍生服务星工程样机；B601 六轴臂、夹爪、主结构、保持释放、太阳翼、航电及感知接口组成同一装配 | 本轮设计决策；总体尺寸由本包参数文件驱动，不声明适配任何指定部署器 |
| 首个具身任务 | 静止刚性靶标识别 → 可达接近 → 低速抓持 → 接触反馈 → 保持 → 释放；先在固定/卸载条件下联调，再扩展运动目标与抓后稳定 | 工程试验任务定义；目标接口直径/边厚、材质、表面和抓持长度待夹爪实测后形成靶标图纸 |
| 任务扩展输入 | 目标质量、完整惯量、相对位姿/角速度、接触刚度/摩擦、容许接触力和抓后运动要求为 `TBD` | 由任务输入表、目标模型/实物测量和夹爪接触试验取得；历史 150 kg / 22 kg 场景不直接充当新样机载荷 |
| 臂数字来源 | `arm_b601_v1.urdf`，6R 主链及现有夹爪；原文件标注为混合来源模型，质量合计 4.695555949342986 kg 是数字输入，不是本轮称重 | 读取 accepted URDF 与既有 ICD；实物序列号、供应商版本、零位、质量、回差和驱动限值需实测绑定 |
| 六轴运动范围 | 按源 URDF：J1 [-2.8,2.8]、J2 [-3.14,0]、J3 [-3.14,0]、J4 [-1.87,1.57]、J5 [-1.57,1.57]、J6 [-3.14,3.14] rad | 数字来源继承；硬止挡余量、控制软限位另按测量误差/停机距离确定，不能用改大源限位取得收拢 |
| 总体构型 | 首候选采用屋顶外部臂收拢走廊与连续内部设备舱；母线初始尺寸 X×Y×Z = 366×226.3×226.3 mm；根部、支承、翼根保留参数化 | 本轮设计初值，不是标准 12U 整机合规声明；与侧置/前置方案使用同一对象集合比较，最终参数以 `design_parameters.json` 为准 |
| 坐标/配置 | S 原点为母线几何中心，+X 为纵向，+Z 朝屋顶，+Y 按右手系；臂根 A0、支承、翼根、TCP、相机和 F/T 均登记 `T_S_*`；几何 mm，URDF m | 首候选根部 frame 旋转 I、平移 [90,0,125.15] mm；名义 BRep 承载接触面另在 z=127.555 mm。各状态沿用同一安装变换，不将 frame 原点当作物理接触面 |
| 主结构输入 | 材料、板厚/梁截面与连接形式为候选；展开臂载荷经臂根转接/承载桥进入框梁，收拢载荷同时经专用支承保持点分流 | 载荷向量、谱、预紧、许用值及公差为 `TBD`；先输出接口截面和连续载荷路径，再根据实选载荷定厚度与紧固 |
| 保持与释放 | 根部刚性安装 + 两处可调整支承站位 + 单独保持/释放功能体；保持件脱开须退出臂首段运动与线束活动空间 | 功能布局，不代表释放器已选型。实际约束自由度、预紧、行程、同步/顺序、断电状态和传感器由联合样件落实 |
| 线束 | 区分母线固定干线、臂根过渡段、关节活动段、腕部服务环和翼根服务环；同一套固定点贯穿运动 | 电缆/套管外径、动态弯曲半径、扭转能力、余长、接头型号/插拔尺寸、循环寿命为 `TBD`；实物样段量测与供应商数据补齐 |
| 内部设备与热 | 设备分供电、电池、计算机/通信、臂驱动与姿控；给设备实体包络、紧固面、连接器、维护拔出和热连接分别保留空间 | F4R1 设备表仅作候选参考；包络不是采购型号。实选设备 CAD/图纸、功耗与散热界面决定详细安装板 |
| 翼和感知 | 两侧翼布局与臂外廊分开；TCP、F/T 与相机安装面/视场/线缆从首轮进入骨架 | 太阳翼可复用设计参考；翼根力矩/线束与末端载荷、传感器型号/标定空间需在同一配置下重新设计 |
| 试制/制造 | 优先试制“框架段—臂根—支承—保持释放—真实线束”组合件；在其安装/释放试验反馈后完善全星加工图 | 加工方法、材料、标准件、测量能力、卸载工装及预算由实际供应方案补齐；本轮 STEP 是布局评审交付 |
| 质量与完成口径 | 每个实例记录 `MEASURED / VENDOR / CAD_ESTIMATE / BUDGET / UNKNOWN`；设备替换包络时删除对应预算行，禁止重复计质量 | 计算质量只属于指定配置。WP01完成=可复建候选、完整对象登记、接口/装配计划及可定位后续工作，不等于零件图完成 |

## 当前决策与下一轮具体零件

1. **屋顶外廊首候选**只用于推进同一配置的联合设计，不预先锁定最终尺寸或路线名称。其选择依据是连续内舱、臂根载荷通路和支承/线束可见性；完整装配包络、翼展与维护空间仍需比较后确认。初始收拢角为 [0,-15,-15,60,-30,0] deg，仅是待几何检查后调整的种子；最终状态读取 `design_parameters.json`。
2. **首轮详细件**按接口拆为：臂根转接板、承载桥/角撑、框梁锚固件、两处鞍座底座和可换接触垫、保持锁扣及支架、释放件支架、释放确认传感器支架、固定线夹、臂根过渡导向件、腕部服务环支架、翼根支架、抽出式设备安装板、F/T 转接与相机支架。每项的对偶接口和待补输入见 `interface_requirements.csv`。
3. **先补会改变几何的输入**：B601 根部实配孔/基准与连接器 → 收拢姿态下可承载的臂壳位置 → 电缆样段尺寸/动态弯曲行为 → 末端及 F/T/相机实选包络 → 设备型号/插拔包络。载荷、热与制造公差同步补齐，分别用于定厚、刚度、预紧和材料设计。
4. **明确证据边界**：包络、参数和导出检查回答总体几何问题；连续运动、结构分析、实体释放和具身闭环各有独立试验记录。未执行项写“计划/待测”，不填预期 PASS。

## 本候选臂根堆叠接口

主 CAD 约定母线屋顶 z=113.15 mm；M3R Stage B 局部 z 范围 [-12,0] mm，整体平移至 z=125.15 mm，因此 B 底面贴合屋顶。Stage A 与 B 共用该局部原点，A 环嵌入 B 槽 5.595 mm。名义 BRep 的 base_link 承载底面在自身局部 z=2.405 mm，因此 B601 根部 frame 也取 [90,0,125.15] mm、旋转 I；A 顶面与名义 BRep 底面相接于全局 z=127.555 mm。根部 frame 与承载接触面是两个不同概念。

这是本轮 CAD 接口复核后的修正，依据见 [INTERFACE_GEOMETRY.json](results/INTERFACE_GEOMETRY.json) 的同原点对偶情况；原先将 base_link 再抬高 2.405 mm 会产生真实几何间隙，应保留为被纠正的情况。accepted STL 基座 bbox 从局部 z=0 起，与该名义 BRep 底面不同；必须完成 BRep/STL 与实物的注册，不能宣称它们已一致。

零件化必须核查槽、环、接触面和紧固件的实际对偶。不得将 Stage A、B 当作两整片顺序叠加到 20 mm，也不得把包围盒重合直接判为实体穿透。上述是名义几何的坐标与接触关系，不是实物接口量测结论；重建后的正式数值由主参数及生成收据保持一致。

## 已读取来源

- [上一轮机械设计与装配实施规划](../../01_project/competition/航天服务星机械设计与装配实施规划_20260905.md)：本轮 WP01 和后续工作包依据。
- [2026-09-05 只读审计总览](../../01_project/competition/PRE_MODE_SWITCH_MECHANICAL_STATE_AUDIT_20260905/00_航天服务星机械设计现状总览.md)、[资产矩阵](../../01_project/competition/PRE_MODE_SWITCH_MECHANICAL_STATE_AUDIT_20260905/02_ASSET_INTEGRATION_VERIFICATION.csv)、[复用清单](../../01_project/competition/PRE_MODE_SWITCH_MECHANICAL_STATE_AUDIT_20260905/07_REUSE_AND_REVALIDATION.md)：已有资产范围及跨配置复用边界。
- [accepted B601 来源登记](../MECHANICAL_ENGINEERING_RELEASE_R2/05_ACCEPTED_B601_URDF_REF.yaml)、[实际 URDF](../cad/spacecraft_layout/arm_b601_v1/arm_b601_v1.urdf)：拓扑、关节限位及文件中的混合来源说明。
- [既有机械 ICD V2](../F3R2_MECHANICAL_CDR_QUALIFICATION_CLOSURE_20260821/03_wp2_mass_interface/MECHANICAL_INTERFACE_CONTROL_DOCUMENT_V2.yaml)：数字臂质量与安装坐标/物理对偶面的区别；旧安装平移不自动迁入新候选。
- [既有 HDRM 工程包](../F3R2_M7_MECHANICAL_FINAL_DESIGN_CLOSURE_V1/wp5_mechanisms/HDRM_ENGINEERING_PACK_V1.yaml)、[夹爪接口登记](../MECHANICAL_ENGINEERING_RELEASE_R2/10_GRIPPER_INTERFACE.yaml)：既有候选的功能划分与实测输入状态；旧预紧/行程不当作本候选实测。
- [F4R1 设备清单 V1](../F4R1_INTERNAL_CONFIGURATION_COMPLETION_V1/50_c1_layout/EQUIPMENT_LIST_V1.yaml)：候选设备与预算/冻结引用的分账方式。

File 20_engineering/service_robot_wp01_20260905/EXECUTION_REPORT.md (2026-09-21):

# WP01 首轮机械设计执行记录

本轮按“现在开始”的直接请求，建立独立候选设计包，实际生成主结构和完整机械臂总体模型。当前交付层级是**参数化设计与静态装配候选**；后续可据此修改零件、试装和联调。旧只读任务没有被当作本轮的停工要求。

## 已形成的结构

- 新建四纵梁、两端框、上下设备板、根部承载板、上下横梁和四根传力立柱。与既有 M3R 两级转接组成 19 个实体的根部结构模块。
- 按同一 accepted URDF 运动学链组织 10 个名义 BRep link，包含掌部和两指；同一根部 frame 贯穿各状态。
- 加入两处支承、保持横梁和释放驱动空间，以及两侧翼/铰链、六类内部设备空间、相机安装初案和固定线束路线空间。完整状态各登记 127 个对象、508 个实体；这个计数包含功能包络和可视电池片，不能理解为已出图的508种零件。
- 保留主参数、三个固定根部布局的比较、按状态的 BOM/质量分账、25项接口表、10步装配与13类验证，以及首批零件化任务。

## 三个状态与真实尺度

| 状态 | 内容 | 名义 BRep 全部对象包络 X×Y×Z / mm |
|---|---|---|
| stowed | 开放停放候选；q=[0,-30,-60,40,0,0]°；双指各15mm；翼折叠 | 504.846 × 357.150 × 757.100 |
| initial_deploy | 同一停放姿态，保持横梁沿Y退出160mm | 504.846 × 357.150 × 757.100 |
| work | q=[0,-80,-70,30,0,0]°；双指各15mm；双翼展开90° | 694.486 × 640.300 × 714.039 |

`stowed` 是延续的文件键，其物理含义已明确为 OPEN_PARKING，不代表紧凑发射收拢。`initial_deploy` 验证的是释放构件位置变化，尚不是已验证的臂展开轨迹。BRep全总装表包括翼/支承/功能空间；LAYOUT_COMPARISON使用accepted STL臂+母线盒，两种包络的对象集合与源几何不同，不能互相替代。

当前翼展开后电池片外法向朝 -Z；太阳矢量、指向约束、遮挡和发电量仍需在任务输入中确定。现阶段没有电功率闭合结论。

## 已执行的核查

| 检查 | 实际结果与范围 |
|---|---|
| 根部结构 | 19实体拓扑/闭合/正体积工具检查无失败；结构实体配对经AABB筛选后5对做OCC布尔，正公共体积均为0 |
| M3R A/B | 同原点嵌套，最小距离0、公共体积0；并非厚度相加的整片叠放 |
| M3R A/B601 | frame在S=[90,0,125.15]mm；名义承载面z=127.555mm；距离约2.19e-13mm、公共体积0 |
| 腕部/掌部 | 使用URDF的精确固定变换，实体距离0、公共体积0；关节原点间距不等于材料间隙 |
| FK到CAD | 直接传4×4矩阵，三状态30个link比对最大误差2.22e-16，容差1e-12 |
| 非相邻臂体 | 停放/作业各35个含臂体配对未发现源三角面相交；包含严格宽阶段剔除及VTK精检，未检验体积完全包含或连续运动 |
| 双指名义BRep | 各15mm位移时48实体，跨组576对包围盒严格分离；OCC最小距离约3.8mm。此项不覆盖不同源的accepted STL双指对 |
| 整体实体工具检查 | 三个状态各508实体中均有6项来自B601源实体的invalidTopology；未报告开壳或非正体积。各状态原始facts、validate与snapshot日志保存在results，工具完成状态见DELIVERY_RECEIPT.json |

6项源拓扑问题位于base_link的第58/59号、link2的第3/4/61/62号实体（0基）。默认ShapeFix保形修复解决0/6，体积和bbox未变，已保留结果并列入后续源实体重建；没有删除它们以取得“通过”。当前完整模型尚未达到全部实体拓扑有效的制造交付水平。

inspect refs的包围盒来自各零件局部AABB八角变换后的汇总，和直接读取世界BRep形状的包络口径不同。本报告尺寸取构建收据中的BRep包络；工具显示范围只用于导航，不当作加工尺寸或实测公差。

已分配质量小计约16.385kg，含4.695556kg的URDF数字臂质量、新金属件的密度体积估算和设备预算。根部结构模块估算3.575391kg。线束、机构、传感器和紧固件分账仍有缺项；这个小计不是整星实测质量。

## 本轮修正保留

1. 原停放种子[0,-15,-15,60,-30,0]°出现非相邻臂体相交，已更换；负结果保存在布局JSON历史字段。
2. 将B601 frame误当承载面会再抬高2.405mm，产生真实间隙；现已改为与M3R共原点，并保留原间隙记录。
3. 早期生成器把extrinsic xyz欧拉角传给intrinsic XYZ构造器，多视图揭示错位；现改成直接矩阵并逐link检验。10:07:49 UTC那组停放PNG已替代，当前评审只采用最终snapshot日志所列文件。

## 下一轮直接做的机械工作

优先完成**根部承载板/纵梁连接—两鞍座—保持释放—真实线束**组合件的零件图和样件。这一组合件同时决定力如何传入星体、收拢能否保持、释放是否退出臂的运动空间，以及线束是否会拉扯或卡住。

先量取真实基准/孔轴和可承载臂壳，再把支承的2mm设置间隙闭合为带可换垫片/调节量的接触；随后确定释放机构的导向、驱动、行程和状态检测，并用真实线束样段检查完整释放与展开过程。紧凑收拢搜索应同时包含支承、翼和线束，不能仅压缩裸臂bbox。

F/T接入、设备安装板与两翼铰链可按接口并行细化。接入F/T必须重建腕部几何、质量和TCP链。详细件清单与完成条件见NEXT_PARTS.md，试装顺序见ASSEMBLY_AND_TEST_PLAN.md。

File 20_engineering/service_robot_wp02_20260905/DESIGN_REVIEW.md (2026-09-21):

# WP02 关键组合件设计评审

本轮已经把根部承载、两处鞍座、保持退出和根部线束安装件做成独立零件与组合件。对象仍为 WP01_ROOF_EXTERNAL_R1；本目录不替换整星既有版本。高立柱、公共悬吊框和手动滑台属于地面装调工装，根桥/M3R属于随星结构候选。当前完成的是数字零件化、数字试装检查和实物试装准备。

## 1. 根部：已有明确零件、接触路径和工具通道

桥板170×202.3×6、上下横梁、四根14×14×2方管和端部定心块分别建模。4根长228的M4类贯通拉杆连接桥板与下横梁，方管端面传递压缩，拉杆承担拉力候选；删除早期贯穿同一中心轴的横销方案。实际预紧、杆材/牙型、接触滑移、局部承压与防松仍需连接设计，不能由圆柱外形证明。

M3R A/B保持同一局部原点，臂根S坐标[90,0,125.15]，名义承载面z127.555。桥板4个Ø6.6孔与M3R四M6类孔、上横梁贯通；新增8个Ø12通道，使M5类螺母/垫圈能从桥板下方装入。先将B定位到桥上、从下方工具通道装M5组件，再以四个M6连接主横梁。根部四M4类连接的实际装入方向和啮合仍按厂家装配/实物确认，不能仅凭孔径推定螺纹。

厂家当前BASE_Plate的64×64四孔与M3R四轴纯刚体拟合最大残差6.248e−5 mm。25.000014°是两套CAD孔坐标的配准量，不是要求把整臂在服务星上额外旋转25°；对称四孔仍有90°等价方向。名义配准、accepted模型和实物装配误差分别登记。[厂家固定版本](https://github.com/Seeed-Projects/reBot-DevArm/tree/8def0ebd8ea0785dcbfc58c00ab176ee42acba5d/hardware/reBot_B601_DM)

长桁端塞的同一加工件可在右端绕其Z轴转180°安装，匹配x=±164横孔；分件STEP为左端局部方向，CAD总装按两端实际孔向生成。连接接触面、螺纹代理和可焊框架交接处分别记录；试装前仍需检查真实紧固件头部工具和防松方式。

## 2. 鞍座：先消除几何穿入，再控制接触自由度

| 对象 | A站 | B站 |
|---|---|---|
| 名义站位S.x | −115 mm | −40 mm |
| 实际候选垫中心S.x | −115 mm | −35 mm，避开局部台阶/紧固特征 |
| 垫中心S.y | ±12 mm | ±12 mm |
| 每垫投影面积 | 4×8 mm | 4×8 mm |
| 鞋顶面S.z | 365.829873 mm | 331.631998 mm |
| 局部平垫最大采样间隙 | 0.125863 mm | 约5.7e−13 mm（名义平面） |
| 装调/独立退出 | Z±8 / 向下30 mm | Z±8 / 向下30 mm |
| 顺应/定位意图 | 主站，Y侧限位按钮按实物调整，Z垫顺应 | X槽允许±4 mm让位，Z垫顺应 |

接触点来自accepted STL三角面射线，不是旧顶点截面最小值。A站首先是局部相切，不能把整个32 mm²都当承压面积；垫压缩、预紧和材料未知。B站变更5 mm是小件接触点偏置，不改变名义支承站或臂根运动学。两下鞍座支承link2，上保持垫为整个折叠臂局部最高处的link3接触候选，必须分别获得壳体/内部支承证据。厂家小STEP局部3 mm厚度不能外推为这些接触区的许用压强。

双鞍座与固定根部是超静定接触问题。反力由根/臂/支架柔度、单侧接触、初始误差和垫压缩共同决定；ROOT_LOAD_PATH.md给出兼容与互补条件，反力/压强/预紧均为null，不假定各承担三分之一。

## 3. 保持退出：已按实体反例修过两轮

原160 mm只覆盖窄横梁局部范围。新机构整体最小Y仍为−59，采样全臂Y最大约100，所以平面几何分离需要159.000001 mm；加候选位置2、超程3、余量5后为169.000001 mm。新Y180在这些预算下还剩10.999999 mm。实际几何误差/关节误差/载荷挠曲未闭合，这个数不是全任务安全裕度。

当前动作顺序为：独立托持/卸载到位 → 两锁销沿−X退出48 → 上垫+Z12、下鞋−Z30 → 两载台+Y180 → 双脱离确认 → 臂首动。锁销为Ø6×64轴加俘获头，有封闭壳/端盖限制脱落；旧18退出会在载台仅动Y0.25时相交，反例已保存。新锁销与载台轴向净距8 mm。

上跨梁抬到完整折叠臂局部包络之上，随后上垫独立退开。导轨由公共x40正侧立柱及z660吊梁承托；负侧保留两柱，立柱顶690。原两站偏置柱相互挡住滑架的问题已消除。锁销座具有固定吊架、丝杆两端支承通过连接块接固定止挡，状态支架实际安装在止挡顶部，标志片接载台顶面。

方导轨/滑块名义几何间隙0.2 mm，顶杆0.3 mm、上导杆0.25 mm。这是尺寸候选，不是润滑/耐磨/污染/公差定型。8 mm手动丝杆是几何与传动接口候选，不依靠电机保持转矩承担保持载荷。金属框件的面接/搭接按可焊或螺接组合候选记录，焊缝、连接件规格和工装承载尚未确认。

状态支架与标志片最终最短间隙23 mm；传感器型号、检测范围/触发行程和冗余布置尚未绑定，因此不能宣称到位检测硬件完成。25个状态机场景是纯离线虚拟输入，失电、未知、单侧、矛盾和旧18误报均不能给臂运动许可。没有向硬件输出命令。

## 4. 线束：复用可核实厂家资料，保留真实线缆缺项

固定commit DM BOM给出了XT30 2+2、200/350 mm总成、弯/直头组合，并提供首关节防拖拽线夹。16 AWG出现在外部电源转接线条目，不能套给全部关节线。[厂家DM BOM](https://github.com/Seeed-Projects/reBot-DevArm/blob/8def0ebd8ea0785dcbfc58c00ab176ee42acba5d/hardware/reBot_B601_DM/readme_zh.md)

本轮新制根部伸出安装板、分体线夹、垫座、连接器滑移托板及立片；厂家线夹原件保存在inputs/vendor_reference。固定锚点和本体/关节锚点都写入参数。根部180 mm与J2 260 mm是待样段验证的自由长度，不能与厂家端到端总长直接等同。

相同锚点/相同材料标记下比较了两种曲线。原二次Bezier最差半径7.028 mm，保留为急弯反例；所选圆弧根部R50.590 mm、J2 R56.022–60.541 mm，26姿态自由长保持。圆弧均为大于180°的大圆弧，端部切线不一定匹配真实插头和夹具，几何半径改善不能替代线缆的受力平衡、弯曲寿命、扭转和摩擦检验。当前分体线夹及连接器托板还是待出口方向绑定的候选，不把显示曲线误记成实配线束。

根部实际护套OD、动态最小弯曲半径、可扭转率、尾壳、端部应变释放与有效自由长仍未从仓库找到。6 mm仅显示代理，4/6/8/10 mm作几何敏感性。J3至腕、翼根活动线没有在这一个关键组合件内完成布线。真实线束结论维持HARNESS_PROXY_ONLY。

## 5. 检查结果与证据范围

最终数字结果统一见results/DELIVERY_RECEIPT.json，原始实算见KEY_GEOMETRY_CHECK、FIXED_GSE_ARM_PATH、ROOT_COMPLIANCE、RELEASE_STATE_MACHINE、CONTACT_REGISTRATION、HARNESS_ANALYSIS。早期实体干涉原样保留为R1，第一轮消除干涉后的R2也保留。

根部柔度采用四柱/两横梁Euler梁模型与理想GSE下端夹固：保留六分量耦合、反力平衡、解析单柱对拍、细分和E/壁厚敏感性。真实桥板/M3R/接触/螺栓柔度未进入，因此不给强度裕度或飞行结论。该分析的单位载荷不是试验载荷建议。载荷分析与结构因子分开处理，NASA资料仅作为方法参考，不作为项目已符合标准的声明。[NASA-STD-5002](https://standards.nasa.gov/standard/NASA/NASA-STD-5002)

完整原臂508实体没有重新生成。显示中的两link凸包只是半透明上下文，源BRep六项缺陷仍按源hash/实体几何指纹登记，不继承成新件有效。原完整臂静态自碰检查不升级为本轮全路径通过。有限姿态之间、完整闭体包含、实际线缆/夹挤和未纳入设备仍有UNKNOWN。

当前4根工装柱与90°展开翼板包络相交，故这一组合件只开展保持/释放/臂首动验证。翼动作应在转独立托持、移除相应GSE后单独验证，不能在同一台架直接执行原整星翼展开动画。

## 6. 实物首件按这个次序继续

1. 用厂家主孔图与实物基准确认DM具体版本、臂根安装朝向和紧固装入方向；完成不承载孔模板/连接器通道检具。
2. 先试装空载公共框、滑台、俘获销、垫退让机构和状态支架，量测48/12/30/180及全行程摩擦和止挡；根桥/拉杆作独立接合与工具检查。
3. 对厂家允许的link2/link3支承区域，用实物表面压印/扫描修订可换垫；按接触兼容模型确认预紧与载荷分配。
4. 使用厂家同端型实际线束样段，绑定出线方向/有效长度/线夹压紧量并做静态和低速反复路径检查；回写参数及几何。
5. 以已确认能力的独立托持装上真实臂，按ASSEMBLY_AND_ACCEPTANCE.md执行P01–P06/V01–V13；每一实测项记录数据和操作者，不沿用数字检查作为实物通过。

可先进入非承载尺寸/加工可行性评审的件：根桥孔/工具通道、A/B可换垫与鞋、空载导向与俘获壳、根部线夹和接头托板。承载加工图仍需材质、公差、连接设计、负载与实物注册。下一批最少补入：确切B601版本/安装照片基准、上下四处可承压区域依据、实际线缆OD/端型与自由长、真实臂质量/质心及台架托持能力。

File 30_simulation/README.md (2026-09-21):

# 仿真、控制与原始机器证据

<!-- WORKSPACE_NAV_START -->
**2026-09-21 目录整理入口：** [本域用途与归档总览](../01_project/governance/WORKSPACE_ORGANIZATION_20260921/WORKSPACE_INDEX.html?domain=30_simulation) · [全项目导航](../PROJECT_MAP.md)。历史来源和证据原位保留；本轮整理不改变设计或科学结论。
<!-- WORKSPACE_NAV_END -->

导航整理：2026-09-06。本域保存模型、计算程序、测试、原始结果及机器裁决。不同模型和版本的结果不互相覆盖，导航不汇总为单一通过状态。

- [冻结 sim 主链与控制场景地图](../10_research/00_project_architecture/simulation_scenario_map.md)：历史主链的场景与证据定位，运行规则按原冻结语境理解。
- [E23 七模态耦合重认证](e23_r2_full_flex_coupled_recert/README.md)及[原始 Gate](e23_r2_full_flex_coupled_recert/results/E23_R2_FULL_FLEX_COUPLED_GATE_V1.json)：R2 柔性证据入口；[E22](e22_r2_full_flex_coupled_diagnostics/README.md)保留早期截断反例与诊断。
- [R2 动力学候选](r2_dynamics_engineering_closure/README.md)、[R2 控制候选](r2_control_engineering_closure/README.md)、[联合闭环](r2_dynamics_control_system_closure/README.md)：各自合同、结果和未闭项的入口。
- [Sim13 后端说明](sim_13_physics_gated_embodied_grasping/v2_system_rebind/runtime_fail_closed_backends_v2/README.md)及[原始注册表 Gate](sim_13_physics_gated_embodied_grasping/v2_system_rebind/runtime_fail_closed_backends_v2/results/SIM13_20_OF_20_GATE_V1.json)：区别后端负控、模型绑定与可执行任务范围。
- [R2 各链原始来源指针](../01_project/current/CURRENT_RELEASE_POINTERS_V1.yaml)：补充机械、安全和控制接口定位。

新模块沿用 `src/`、`tests/`、`results/`、`docs/` 的自包含组织。原始失败、UNKNOWN 和受限结果留在各拥有者目录；WP03 新工程候选不能直接继承旧仿真结论。

## 目录职责

以下分类只说明资产用途；文中的历史执行限制按原记录日期理解。目录内不同版本、独立复算和原始结果保留原位。本轮仅对派生说明合并、对确认副本去重。

| 子目录 | 用途 | 保留范围 |
|---|---|---|
| [asm_00_interface_preflight](asm_00_interface_preflight/README.md) | 历史前检合同 | 接口前检、成功评价合同及原始受限裁决。 |
| [common](common/) | 共享依赖 | 刚体与捕获冲量公共算法；保留源码。 |
| [control_01_end_effector_tracking](control_01_end_effector_tracking/README.md) | 冻结基线与独立验证 | Wave 1 控制或安全合同；历史失败及限制保留。 |
| [control_02_base_attitude](control_02_base_attitude/README.md) | 冻结基线与独立验证 | Wave 1 控制或安全合同；历史失败及限制保留。 |
| [control_r2_integrated_candidate](control_r2_integrated_candidate/README.md) | 现存候选支路 | 按目录内具名合同和结果使用；不合并不同运行或独立审计。 |
| [current_r2_digital_host_capture_data_v1](current_r2_digital_host_capture_data_v1/README.md) | 现存候选支路 | 按目录内具名合同和结果使用；不合并不同运行或独立审计。 |
| [dynamics_control_prebind_r1](dynamics_control_prebind_r1/README.md) | 现存候选支路 | 按目录内具名合同和结果使用；不合并不同运行或独立审计。 |
| [e15_ancf_certification](e15_ancf_certification/README.md) | 历史独立诊断 | 覆盖、ANCF 认证和同步捕获的独立证据。 |
| [e15_core_coverage](e15_core_coverage/README.md) | 历史独立诊断 | 覆盖、ANCF 认证和同步捕获的独立证据。 |
| [e16_sync_capture](e16_sync_capture/README.md) | 历史独立诊断 | 覆盖、ANCF 认证和同步捕获的独立证据。 |
| [e17_b601_mission_trajectory_candidates](e17_b601_mission_trajectory_candidates/README.md) | 工程诊断谱系 | 候选输入、不同模型分支及重认证各自保留。 |
| [e18_b601_mission_input_branches](e18_b601_mission_input_branches/README.md) | 工程诊断谱系 | 候选输入、不同模型分支及重认证各自保留。 |
| [e19_b601_mission_branch_diagnostic_evaluation](e19_b601_mission_branch_diagnostic_evaluation/README.md) | 工程诊断谱系 | 候选输入、不同模型分支及重认证各自保留。 |
| [e20_b601_independent_mass_branch_coupled_diagnostics](e20_b601_independent_mass_branch_coupled_diagnostics/README.md) | 工程诊断谱系 | 候选输入、不同模型分支及重认证各自保留。 |
| [e21_m7_r2_arm_placement_rigid_coupled_diagnostics](e21_m7_r2_arm_placement_rigid_coupled_diagnostics/README.md) | 工程诊断谱系 | 候选输入、不同模型分支及重认证各自保留。 |
| [e22_r2_full_flex_coupled_diagnostics](e22_r2_full_flex_coupled_diagnostics/README.md) | 工程诊断谱系 | 候选输入、不同模型分支及重认证各自保留。 |
| [e23_r2_full_flex_coupled_recert](e23_r2_full_flex_coupled_recert/README.md) | 工程诊断谱系 | 候选输入、不同模型分支及重认证各自保留。 |
| [module_cards](module_cards/README.md) | 合并认知入口 | 主题知识卡集中于 README；不替代原始证据。 |
| [r2_control_engineering_closure](r2_control_engineering_closure/README.md) | 现存候选支路 | 按目录内具名合同和结果使用；不合并不同运行或独立审计。 |
| [r2_dynamics_control_system_closure](r2_dynamics_control_system_closure/README.md) | 现存候选支路 | 按目录内具名合同和结果使用；不合并不同运行或独立审计。 |
| [r2_dynamics_engineering_closure](r2_dynamics_engineering_closure/README.md) | 现存候选支路 | 按目录内具名合同和结果使用；不合并不同运行或独立审计。 |
| [r2_mujoco_free_floating_precontact_v1](r2_mujoco_free_floating_precontact_v1/README.md) | 现存候选支路 | 按目录内具名合同和结果使用；不合并不同运行或独立审计。 |
| [safety_00_runtime_gate](safety_00_runtime_gate/README.md) | 冻结基线与独立验证 | Wave 1 控制或安全合同；历史失败及限制保留。 |
| [sim_01_free_flight](sim_01_free_flight/) | 冻结科学基线 | 保留模型、配置、原始数据、测试及裁决。 |
| [sim_02_target_tumble](sim_02_target_tumble/) | 冻结科学基线 | 保留模型、配置、原始数据、测试及裁决。 |
| [sim_03_arm_reaction](sim_03_arm_reaction/) | 冻结科学基线 | 保留模型、配置、原始数据、测试及裁决。 |
| [sim_04_capture_corridor](sim_04_capture_corridor/) | 冻结科学基线 | 保留模型、配置、原始数据、测试及裁决。 |
| [sim_05_free_floating_arm](sim_05_free_floating_arm/) | 冻结科学基线 | 保留模型、配置、原始数据、测试及裁决。 |
| [sim_06_capture_impulse](sim_06_capture_impulse/) | 冻结科学基线 | 保留模型、配置、原始数据、测试及裁决。 |
| [sim_07_ancf_flexible](sim_07_ancf_flexible/) | 冻结科学基线 | 保留模型、配置、原始数据、测试及裁决。 |
| [sim_08_detumble_actuator_budget](sim_08_detumble_actuator_budget/) | 冻结科学基线 | 保留模型、配置、原始数据、测试及裁决。 |
| [sim_09_grasp_evaluator](sim_09_grasp_evaluator/) | 冻结科学基线 | 保留模型、配置、原始数据、测试及裁决。 |
| [sim_10_mission_feasibility](sim_10_mission_feasibility/) | 冻结科学基线 | 保留模型、配置、原始数据、测试及裁决。 |
| [sim_11_coupled_dynamics](sim_11_coupled_dynamics/) | 冻结科学基线 | 保留模型、配置、原始数据、测试及裁决。 |
| [sim_12_strategy_feasibility](sim_12_strategy_feasibility/) | 冻结科学基线 | 保留模型、配置、原始数据、测试及裁决。 |
| [sim_13_physics_gated_embodied_grasping](sim_13_physics_gated_embodied_grasping/README.md) | 混合谱系 | V1 历史 bootstrap 与后续候选/独立后端分目录保留。 |
| [sim_13_viability_extension_r1](sim_13_viability_extension_r1/README.md) | 现存候选支路 | 按目录内具名合同和结果使用；不合并不同运行或独立审计。 |
| [sim_14_m4_digital_prototype_grasping](sim_14_m4_digital_prototype_grasping/README.md) | 历史数字样机支路 | M4/M5 诊断合同；不替代新的整星工程候选。 |
| [sim_15_m5_geometry_gated_grasping](sim_15_m5_geometry_gated_grasping/README.md) | 历史数字样机支路 | M4/M5 诊断合同；不替代新的整星工程候选。 |

## 早期 v0 模型说明（2026-07-09）

本节吸收原 `README_sim_baseline_v0.md`。以下质量、软件环境和简化模型结论只属于当时 v0 基线，不能用于替代 B601 完整模型或 WP03 工程候选。

## Stage-2 v0 Simulation Baseline

> Role: v0 digital-prototype simulation baseline | Last synced: 2026-07-09
> Physics implemented directly in numpy/scipy (Basilisk/SPART/42 not installed locally;
> they are the future cross-validation upgrade). All sims read mass/CoM/inertia from
> `../20_engineering/stage1_spacecraft_layout/04_mass_inertia_budget/mass_inertia_budget_v1.csv`
> and use the frozen coordinate SSOT (frames S/M/T/D). Run with the Anaconda python.

### Layout
```
30_simulation/common/rigid_body.py      shared: inertia loader, torque-free Euler + quaternion, H/E diagnostics
30_simulation/sim_01_free_flight/       servicer_12U_v0 uncontrolled attitude drift
30_simulation/sim_02_target_tumble/     target_debris_v0 tumble + grasp-feature visibility
30_simulation/sim_03_arm_reaction/      manipulator-induced base reaction (reduced free-floating model)
```
Each `sim_XX/` has its script and `results/{*.csv,*.png}`. One-click: `python 30_simulation/sim_XX_*/sim_XX_*.py`.

### Results & validation

| sim | headline result | physics check |
|---|---|---|
| sim_01 | 120 s attitude/rate history for the 12U servicer | angular momentum \|H\| and rotational KE E conserved to ~0 (machine precision) |
| sim_02 | tumbling debris grasp feature visible only ~50% of the time to a +X-approaching servicer | \|H\|, E conserved |
| sim_03 | **arm reach induces ~13.1 deg peak base attitude disturbance**, returning to 0 after a reciprocal retract | exact angular-momentum conservation (reversible) |

### Key v0 finding
Manipulator motion cannot be neglected: on the 12U v0 configuration with a simplified planar arm,
a single reach swings the free-floating base by ~13 deg. A 5 deg base-pointing budget is therefore
**infeasible with naive (non-reaction-aware) arm motion** — motivating reaction-null-space / momentum-
compensated planning (see sim_04 capture corridor).

### Modeling honesty
- sim_03 is a **reduced planar free-floating model** (angular-momentum conservation about the instantaneous
  system CoM; base translation neglected). Full 3D generalized-Jacobian dynamics via SPART is future work.
- Target/debris inertia is self-defined (confidence low), never claimed as measured (risk RA-003).

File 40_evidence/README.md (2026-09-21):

# 证据汇总与展示工件

<!-- WORKSPACE_NAV_START -->
**2026-09-21 目录整理入口：** [本域用途与归档总览](../01_project/governance/WORKSPACE_ORGANIZATION_20260921/WORKSPACE_INDEX.html?domain=40_evidence) · [全项目导航](../PROJECT_MAP.md)。历史来源和证据原位保留；本轮整理不改变设计或科学结论。
<!-- WORKSPACE_NAV_END -->

导航整理：2026-09-06。本域保存跨模块汇总、图表、媒体、离线回放和冻结展示副本。展示及汇总的来源仍由原始结果拥有者负责。

- [展示与冻结工件](artifacts/)和[汇总表](tables/)：按对应生成来源与时间阅读。
- [研究仪表板](artifacts/visualization/project_visualization_v1_research.html)：既有研究证据的离线汇总；[构建工具说明](../70_tools/research_dashboard/README.md)。
- [历史比赛回放](artifacts/competition_convergence/)：比赛展示材料，不代表后续机械或硬件完成状态。
- [原始仿真证据](../30_simulation/README.md)与[工程候选证据](../20_engineering/README.md)：核查表图、媒体引用的模型和机器记录。

总览、截图和冻结副本不替代源 Gate、配置或实际试验记录。

## 子目录与保留边界

| 子目录 | 实际用途 | 本轮处置 |
|---|---|---|
| [artifacts/](artifacts/) | 离线展示、资格预检展示、历史比赛回放及冻结证据快照 | 保留生成物与其来源链；不把画面或副本当作新机器结果 |
| [c1_evidence/](c1_evidence/) | B51/F3 各阶段的原始 CAD/CAE 接口诊断、载荷与执行证据，含历史辅助源码 | 独有诊断、失败、见证和源文件保留；未作物理正确性复审 |
| [tables/](tables/) | 有日期的主张映射、文献扫描与研究规划汇总表 | 保留原表；表中的状态由引用的原始记录解释 |

旧域说明中重复的展示与 Gate 责任声明已并入上文；原始字节可从本轮 SQLite 备份恢复。各报告若主题相近但绑定不同构型、阶段、试验或见证，不作为重复文件删除。

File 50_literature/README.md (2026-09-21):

# 文献主清单、阅读卡与全文

<!-- WORKSPACE_NAV_START -->
**2026-09-21 目录整理入口：** [本域用途与归档总览](../01_project/governance/WORKSPACE_ORGANIZATION_20260921/WORKSPACE_INDEX.html?domain=50_literature) · [全项目导航](../PROJECT_MAP.md)。历史来源和证据原位保留；本轮整理不改变设计或科学结论。
<!-- WORKSPACE_NAV_END -->

导航整理：2026-09-06。本域统一保存文献题录、核验记录、阅读卡和本地全文；不在导航中重复容易漂移的数量。

- [题录与核验主清单](references/manifest.yaml)：文献身份、本地文件和来源状态。
- [阅读卡索引](references/notes/INDEX.md)与[BibTeX](references/refs.bib)：阅读与引用入口；索引文字中的日期和计数仍需对照主清单。
- [本地 PDF](pdf/)：按文献分类保存全文。
- [文献工作流派生状态](../10_research/knowledge_base/papers/controller_state.yaml)：辅助安排阅读，不是第二份题录主清单。
- [历史补充论文来源](#legacy-supplemental)：保留迁移来源关系。

全文、阅读卡、题录及引用用途不同；同名或重复引用不等于内容可以互相替代。

## 历史补充论文来源

REORG-01-R 已将原“补充论文”目录中的 21 份 PDF 归并到 [pdf/](pdf/)，统一采用 `NN_category/bibkey.pdf` 命名。题录、页数、SHA-256 与来源记录以[主清单](references/manifest.yaml)为准；原归并过程见[核验报告](references/reorg01r_report.md)。不再建立平行 PDF 副本。

2026-09-06 将原 `legacy_supplemental/README.md` 的迁移说明并入本节，并移除该空目录；原文完整字节保存在整理账本的 SQLite 快照中。

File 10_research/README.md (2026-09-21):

# 研究问题、论文与证据导航

<!-- WORKSPACE_NAV_START -->
**2026-09-21 目录整理入口：** [本域用途与归档总览](../01_project/governance/WORKSPACE_ORGANIZATION_20260921/WORKSPACE_INDEX.html?domain=10_research) · [全项目导航](../PROJECT_MAP.md)。历史来源和证据原位保留；本轮整理不改变设计或科学结论。
<!-- WORKSPACE_NAV_END -->

2026-09-06 整理。本域负责问题、方法、合同、论文结构与证据关系。具体结论回到模型、配置和原始结果；本页不复制会过期的 PASS 数量、任务许可或全项目状态。

优先入口：[任务与历史背景](knowledge_base/project_context/README.md) → [知识库](knowledge_base/README.md) → [Q1–Q6 问题树](research_questions/README.md)。工程输入见[20_engineering](../20_engineering/README.md)，原机器证据见[30_simulation](../30_simulation/README.md)，文献来源见[manifest](../50_literature/references/manifest.yaml)。

| 主题 / 路径 | 用途与范围 |
|---|---|
| [00_project_architecture](00_project_architecture/) | 六层架构、叙事、论文、场景、实验与 Agent 冻结计划 |
| [research_questions](research_questions/)、[theory_graph](theory_graph/)、[contribution_map](contribution_map/) | Q1–Q6、理论假设、候选贡献与主张证据关系；不替代求解模型 |
| [paper1_architecture.md](paper1_architecture.md) | Paper1 结构规划，不是论文正文或新结果 |
| [research_os_01](research_os_01/)、[research_os_02](research_os_02/) | 初始化审阅、Q6 范围与证据生成计划，保留原日期 |
| [space_embodied_robotics](space_embodied_robotics/README.md) | 长期路线、任务分类、迁移、Physics-Gated Agent 与分阶段数字身体合同 |
| [knowledge_base](knowledge_base/README.md) | 领域知识、纸面来源、状态沿革与方法导航；[旧结构方法](knowledge_base/spacecraft_mechanical_design/legacy_structure_methods_20260728.md)已合并 |
| [sim_12](sim_12/) | Gate0 动量账本、预注册与审计；实施结果在仿真域 |
| [partner_requirement_closure](partner_requirement_closure/) | Wave0 规划、Wave1 结果/终裁与任务卡 |
| [on_orbit_assembly](on_orbit_assembly/) | 接口、接触、分阶段控制、双任务文献与任务合同 |
| [framework_convergence](framework_convergence/) | 六层关系、证据矩阵、红队记录及下一波历史任务卡 |
| [competition_convergence](competition_convergence/) | 离线三场景、验证器、固定合同与比赛机器记录 |
| [control](control/)、[rom](rom/)、[vla](vla/)、[integration](integration/) | 控制、保真度、候选协议和系统接口专题计划；不能从文件存在推得实施完成 |
| [panel](panel/) | 帆板参数草案和敏感性矩阵 |
| [mechanical_design_progress_gallery_20260729](mechanical_design_progress_gallery_20260729/) | 带日期的原生机械图示与诊断日志 |
| [B5.0](comp_prot_03_a4_b5_0_b601_space_manipulator_engineering_cad/)、[B5.1](comp_prot_03_a4_b5_1_b601_interface_closure_articulation_stowage/)、[B5.1R1](comp_prot_03_a4_b5_1r1_b601_canonical_interface_native_articulation_rework/) | 各阶段独有任务范围与合同，不是当前自动执行指令 |

架构六层的职责是：L0 任务可行性/策略；L1 SAFE 证据核；L2 确定性控制；L3 刚柔世界模型；L4 具身候选生成；L5 地面验证。模型通过、候选生成、控制实施与硬件资格分别取证，不由某层结论覆盖其它层。

数字身体路线的关键入口是 [V1 候选合同](space_embodied_robotics/space_embodied_agent_v1_contract.md)、[平台接口](space_embodied_robotics/comp_prot_02/README.md)、[A0/A1 来源审阅](space_embodied_robotics/comp_prot_03_a0_a1/README.md)、[A2 候选一致性](space_embodied_robotics/comp_prot_03_a2_candidate_model_review/README.md)与[四层数字身体方法](space_embodied_robotics/comp_prot_03_a3_g0_digital_body_method/README.md)。这些入口内状态按各自日期理解，不能覆盖后续 WP 候选或本次用户指令。

[research_state_v4.md](research_state_v4.md)是 2026-07-20 的冻结机器输入，保持原字节；v3 与三份 project_context 摘要已合并为[任务知识](knowledge_base/project_context/README.md#history)。本文原重复历史导航已吸收为上表，原字节仍在共享账本。历史阈值、哈希和负结果保留，不由整理升级。

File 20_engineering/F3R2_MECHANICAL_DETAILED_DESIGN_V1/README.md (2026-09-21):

# Phase M3 — Mechanical Detailed Design Closure

This workspace advances the hash-bound `V5R_NEUTRAL_OPERATIONAL_BASELINE` into a
working `V6_ENGINEERING_DETAILED_MECHANICAL_BASELINE`. It is an engineering
design workspace, not a Mechanical CDR, manufacturing release, qualification
baseline, or flight release.

The executable loop is:

1. audit and freeze every design input;
2. map requirements to verification evidence;
3. build parameter-controlled neutral geometry;
4. validate geometry and interfaces independently;
5. close mass, material, process, and tolerance inputs without zero-filling;
6. evaluate the FEA entry gate;
7. issue a fail-closed detail-design gate and feed every blocker into the next loop.

Current claim boundary: parameterized working models and engineering records are
authorized. Formal flight-load FEA, margins of safety, manufacturing release,
qualification credit, and flight acceptance remain `HOLD`.

Primary control files:

- `00_authority/M3_PHASE_AUTHORITY_AND_BOUNDARY.yaml`
- `00_authority/MECHANICAL_LOOP_ENGINEERING_CONTROL_V1.yaml`
- `01_requirements/MECHANICAL_DETAIL_DESIGN_REQUIREMENTS_V1.yaml`
- `01_requirements/MECHANICAL_DETAIL_DESIGN_VCD_V1.csv`
- `07_fea/FEA_ENTRY_CRITERIA_AND_MODEL_PLAN_V1.yaml`
- `12_gate/MECHANICAL_DETAIL_DESIGN_GATE.json`

All numerical records shall carry units, source classification, and uncertainty
status. Unknown values remain `null`/`HOLD`; a CAD number is not a measurement.

## M3-L01 outcome

The first closed-loop iteration is complete. Artifact integrity passed and the
bounded token `M3_L01_CONTROLLED_WORKING_BASELINE_ESTABLISHED` was issued. The
overall `MECHANICAL_DETAIL_DESIGN_GATE` remains `HOLD`; its release token was not
issued. Seven mandatory design-release subgates remain open, and formal FEA run
count remains zero.

See `11_validation/M3_L01_ITERATION_RECEIPT.json` for immutable hashes and
`12_gate/NEXT_LOOP_ACTION_REGISTER.csv` for the next evidence-acquisition loop.

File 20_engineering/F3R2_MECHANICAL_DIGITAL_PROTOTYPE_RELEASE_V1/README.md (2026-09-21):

# F3R2 Mechanical Digital Prototype Release V1

This workspace is the M4 controlled continuation of the M3 detailed-design
working baseline.  Its purpose is to establish a reproducible, versioned
mechanical digital prototype and a fail-closed exchange contract for bounded
dynamics/grasping research.

It is **not** a manufacturing, qualification, launcher-integration, or flight
release.  Formal FEA is prohibited until the structural-analysis entry gate is
explicitly passed by controlled load, material, boundary-condition, fastener,
contact, mass-property, and acceptance authorities.

Unknown values remain `null` with an explicit `HOLD`; no zero filling is
permitted.  The 6 GiB memory gate remains failed during this phase.  Any
FreeCAD execution is a bounded Owner Override run and must be recorded as such.

## Controlled state path

`M3_CONTROLLED_WORKING_BASELINE -> M4_DIGITAL_PROTOTYPE_WORKING_RELEASE`

From M4, two independently earned branches are tracked:

- `STRUCTURAL_ANALYSIS_READY` remains `HOLD` until the physical structural-entry
  authorities close.
- `SIM14_BOUNDED_DYNAMICS_READY` may pass only as a software/ideal-rigid-lock
  diagnostic; it does not depend on, or substitute for, structural release.

Production contact dynamics and physics-gated RL require the applicable
physical, structural, mass-property, contact, and validation gates to close.

## Release entry points

- `12_release/M4_RELEASE_SUMMARY.md` — engineering outcome, evidence and next loop.
- `12_release/MECHANICAL_DIGITAL_PROTOTYPE_RELEASE_GATE_V1.json` — machine-readable scoped tokens and mandatory HOLDs.
- `12_release/M4_REQUIREMENTS_VERIFICATION_MATRIX_V1.csv` — requirement-to-evidence closure.
- `12_release/M4_NEXT_LOOP_ACTION_REGISTER_V1.yaml` — ordered M5 physical-authority backlog.
- `12_release/M4_OUTPUT_MANIFEST_V1.json` — final M4 and Sim14 output hashes.

The later states are earned independently.  A passed artifact-integrity test
does not imply that missing physical authorities have been closed.

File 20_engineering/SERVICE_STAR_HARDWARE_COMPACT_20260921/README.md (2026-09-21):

# 航天服务星与 B601 机器人硬件数字样机

本目录是2026-09-21从本机工程库提取的精简设计工作副本，范围仅为机械、电气线束、能源热控和动力推进。它不包含航天动力学、任务控制、RL/VLA或上层规划研究。

当前基线：R6H水平安装机械候选、R5E电气候选、R2/R3线束与机械臂接口、B2热方案及推进接口准备。整理与复制不会把候选设计变成制造或飞行放行。

## 按模块打开

| 模块 | 内容 | 当前边界 |
|---|---|---|
| [机械打开指南](01_mechanical/MECHANICAL_OPEN_GUIDE.md) | [当前R6H总装](01_mechanical/native/SERVICE_STAR_SERVICE_R6H.SLDASM)、所需零件与子装配、几何/展示及安装说明 | MAIN水平安装；AUX/STOP尚未完成安装；完整材料、质量、公差与强度未闭合 |
| [电气与线束](02_electrical/) | MAIN/AUX/STOP KiCad源文件与库、候选BOM、接口及线束表 | R5E选型尚未全部落实为功能电路/PCB；不可直接据此上电或下单制造 |
| [能源与热控](03_power_thermal/) | 电源与负载设计、热结构目标、热路径与待验证参数 | 整星电热预算和当前布局的热验证尚未闭合 |
| [动力与推进](04_propulsion/) | 候选比较、安装空间、管路/电接口需求、OEM输入表及下一步工作单 | 型号未冻结，实际推进硬件接口尚待厂家资料 |
| [范围与来源](00_release/) | 文件来源映射、完整性检查、来源许可说明、已知缺口 | 文件整理检查不替代各模块的工程验收 |

先阅读 [硬件未完成项](00_release/OPEN_ITEMS.md) 和 [公开使用说明](00_release/PUBLICATION_NOTES.md)。机械与电气目录各自的说明记录打开方法、版本、依赖和本次验证结果。原始工程证据在来源库保持原位；仅白名单文件进入本目录。

## GitHub使用范围

本目录拟作为一个独立硬件仓库的内容根目录，不应把上层工作区或原有`.git`一并上传。这里没有复制原仓库历史、环境转储、私人协作资料、软件安装器、整套论文或研究控制代码。

本次是本地整理交付，尚未创建/推送GitHub仓库。公开前需按来源清单确认第三方CAD/库的再分发范围及自有设计的许可；不能对全部文件自动套用单一MIT许可证。文件存在于本目录不等于已获得额外授权。

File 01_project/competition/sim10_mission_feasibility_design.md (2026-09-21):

# sim_10 任务可行域边界（Mission Feasibility Boundary）设计书 — 2026-07-15

> ⚠ 历史设计稿（2026-07-15）：sim_10 **已实现并 `SIM10_GATES_PASS`**
> （`30_simulation/sim_10_mission_feasibility/results/sim_10_gate_check.json`）。本文"未实施"
> 表述为设计期原文，仅作溯源；现行结论见 `项目现状总览_20260720.md` 与该 Gate JSON。

状态：**设计文档，未实施**。定位：把 REPEAT_CORE 的"点结论"（μ=6.25 碎片在 2°/s 预算下全策略不可行）
推广为**无量纲设计空间中的可行域边界**——Paper 1 的第一主图生成器。
铁律：sim_10 为独立模块（建议 `30_simulation/sim_10_mission_feasibility/`），**只读 import** `30_simulation/common/capture_impulse.py`
与 `sim_08` 公式，不修改 sim_01–09 任何文件；阈值取冻结 registry（SHA-256 绑定），禁止放宽。

## 1. 物理链与门序（全部来自已验证求解器）

```
目标状态(ω_t, I_t) ──rigidize()──▶ ω⁺, |H_c|          [sim_06 已验证, 25/25]
                                      │
              门1: 捕获后转速  |ω⁺| ≤ ω_budget (2°/s, registry)
              门2: 轮组容量    |H_c| ≤ n_w·h_w            [sim_08]
              门3: 推力器冲量  J_req = |H_c|/l_T ≤ J_avail [sim_08]
              门4: 消旋时间    t_d = |H_c|/τ ≤ t_max       [sim_08]
```
共轴近似下的解析骨架（用于闭式边界，与精确解对照）：
`ω⁺/ω_t ≈ κ_ω = I_t / (I_t + I_s + ΔI_Steiner(μ, 几何))`，`|H_c| ≈ I_t·ω_t`（μ 大时目标主导）。

## 2. 无量纲参数定义（Part 1 交付）

| 符号 | 定义 | 物理含义 | 备注 |
|---|---|---|---|
| μ | m_t/m_s | 质量比（用户指定主轴） | 本项目两锚点：卫星 0.92、碎片 6.25 |
| ι | Ī_t/Ī_s | 惯量比（真正主导 ω⁺ 的量） | 碎片 ι≈211——μ 与 ι 经几何类别映射 |
| ω̂ | ω_t/ω_budget | 翻滚率/预算比 | 门1 的直接变量 |
| h* | I_t·ω_t/(n_w·h_w) | 目标角动量/轮组容量（用户 h*） | h*≤1 = 轮组可消化 |
| j* | J_avail·l_T/(I_t·ω_t) | 可用/所需推力器冲量比（用户 j*） | j*≥1 = 推力器可消化 |
| λ | r_g/L_t | 抓点杠杆比 | 控制 r×mv 耦合与 Steiner 增量 |
| α | 速度匹配度 | 0=直撞, 1=完全同步 | E16 已证 α 改冲量不改 ω⁺ 可行性 |

几何类别映射 ι(μ)（避免 μ、I_t 双自由度撒谎）：三类等密度缩放
`I_t = c_g·m_t·L_t²，L_t ∝ (m_t/ρ_g)^{1/3}`：G1 细长上面级（c、ρ 按 target_debris_v0 标定）、
G2 立方星本体（按 target_satellite_v0 标定）、G3 致密紧凑体。两锚点必须精确落回 sim_06 数值。

## 3. 扫描空间（Part 2 交付）

| 维度 | 网格 | 数量 |
|---|---|---|
| μ | log[0.05, 25] | 25 |
| ω_t | log[0.1, 10] °/s | 20 |
| 几何类 | G1/G2/G3 | 3 |
| λ | {0.2, 0.5, 1.0} | 3 |
| 执行机构档 | 轮组{3×15, 3×100 mN·m·s} × 推力器{冷气60s, 单元220s}×l_T{0.05,0.17} | 组合按 sim_08 yaml |
| α | {0, 1} | 2 |

主图切片 25×20=500 点/图（rigidize 微秒级，全空间秒-分钟级，无成本压力）。
每点输出：ω⁺（**精确矢量解**）、|H_c|、四门裁决、binding gate、与共轴解析近似的偏差 δ_analytic。

## 4. 边界与区域定义（Part 3 交付）

区域标签（fail-closed，颜色语义沿用 fig_v07 纪律，不做红绿二分）：
- `WHEELS_ONLY_FEASIBLE`：门1∧门2 通过（无需消耗推进剂）
- `THRUSTER_REQUIRED_FEASIBLE`：门1∧¬门2∧门3∧门4
- `INFEASIBLE_RATE`：¬门1（捕获后转速超预算——REPEAT_CORE 的 binding）
- `INFEASIBLE_RESOURCE`：门1 通过但 ¬(门3∧门4)
边界=区域交界等值线；**双层绘制**：解析近似边界（虚线）vs 精确矢量解边界（实线），
两线偏移量即 CL02（标量/简化模型误差）在任务级的放大呈现。

## 5. 实验设计与验收（Part 4 交付）

| 实验 | 内容 | 验收 |
|---|---|---|
| X1 主图 | (μ, ω̂) 平面 ×3 几何类，标注两任务锚点 | 锚点 ω⁺ 与 sim_06 CSV 差 <1e-6；碎片点落在 INFEASIBLE_RATE，卫星点落在 WHEELS_ONLY |
| X2 杠杆敏感性 | λ 三档边界漂移 | 边界随 λ 单调性检查 |
| X3 执行机构档 | 轮组/推力器档位叠加 | 3.65 N·m·s 行与 sim_08 CSV 逐位对拍 |
| X4 解析 vs 精确 | δ_analytic 场 | 共轴工况 δ→0；大 λ 处偏差最大且方向与 CL02 一致 |
| 回归 | t_s10_anchor / t_s10_determinism / t_s10_monotonic / t_s10_registry_hash | 全 PASS；registry 哈希锁定，thresholds_widened=False |

## 6. 论文 Figure 设计（Part 5 交付）

- **Fig-F1（候选论文主图）**：Mission Feasibility Map——x=μ(log)，y=ω̂，四区域着色 + 解析/精确双边界 +
  卫星/碎片任务星标 + "REPEAT_CORE 216例" 点云投影。科学目的：一图回答"什么目标值得抓"。
  数据源：sim_10 主扫描 CSV + e16 结果投影。预期结论：存在清晰的 (μ,ω̂) 不可行楔形区，碎片任务深处其中。
- **Fig-F2**：h*–j* 资源平面（同一扫描换轴）：轮组线 h*=1 与推力器线 j*=1 划分三资源区。
- **Fig-F3**：λ 敏感性边界族——抓点杠杆如何移动可行边界（连接 Paper 2 的选点主题）。
- **Fig-F4**：解析-精确偏差场 δ_analytic(μ,λ)——简化模型在任务级判定上何时给出错误结论。

## 7. 明确不做

不重跑 ANCF（柔性门在 P0-B 通过前不进入 sim_10 判据，图注声明 FLEX=UNKNOWN 不改变刚体边界的保守性方向）；
不做不确定性分位（E2 范围）；不改任何阈值；不引入学习组件。

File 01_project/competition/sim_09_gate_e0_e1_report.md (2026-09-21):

# sim_09 抓取候选评价器 — Gate E0 + E1 报告

日期：2026-07-13 ｜ 分支：`feat/sim09-grasp-evaluator`（基线 HEAD `2f954fd`）
执行：Gate E1「确定性 G0/G1/G2 薄切片」（72 工况，全确定性，无采样）

---

## 1. Gate E0 摘要（已提交 `2f954fd`）

评价器骨架 `30_simulation/sim_09_grasp_evaluator/src/`：

- **契约**（`contract.py`）：`GraspCandidate` → `evaluate()` → `GraspEvaluationResult`（21 个结果字段）；
  `scenario_hash` = 全部输入的规范化 JSON 的 sha256[:16]（1e-9 舍入，对任一输入 1e-6 扰动敏感，t7 验证）。
  **无 overall_score**（E0 裁定：硬约束筛选 → 单项指标 → Pareto，聚合分数仅保留注释占位）。
- **只读适配器**（`adapters.py`）：五个已验证求解器一律 import、绝不复制 —— capture
  （`30_simulation/common/capture_impulse.py` rigidize/点接触）、base reaction（sim_05 `FreeFloatingB601`）、
  flexible（sim_07 ANCF `sim_07a_task_response`）、actuator（sim_08 代数式）、propagation
  （`30_simulation/common/rigid_body.py`）。每段输出 provenance{module, commit, units, wall_time_ms}。
- **IK**（`ik.py`）：多起点 DLS（固定种子 20260712，逐位确定），pose_6d / approach_5d / position_3d；
  **碰撞**（`collision.py`）：胶囊-图元 SDF，几何假设 A1–A7 全部声明于
  `20_engineering/config/grasp_evaluator/collision_geometry_v1.yaml`。
- **锚定回归 7/7 PASS**（`30_simulation/sim_09_grasp_evaluator/results/anchor_report_e0.md`）：
  t1 冲量锚（sim_06/08 CSV，残差 3.0e-5）；t2 IK 往返（3.7e-8 rad）；t3 动量守恒（1.6e-17）；
  t4 ANCF 锚（sim_07a 标称，9.0e-6 相对）；t5 传播四性质（2.3e-11）；t6 推进剂逐位相等；
  t7 双重求值逐位一致 + 哈希敏感性。
- E0 发现并记录 **+X 腕部奇异**：抓取点若落位在 S 系 x 轴上（z=0），任务雅可比条件数 ~2–3e4；
  E0 默认落位 `capture_point_S=[0.95, 0, -0.10]` 避开（常规条件数 ~19–27）。E1 沿用该落位策略。

## 2. ANCF 运行成本审计摘要（口径澄清）

裁决文件：`30_simulation/sim_09_grasp_evaluator/results/ancf_cost_audit_verdict.md`（15 工况实测）。

- **口径澄清**：早先「每候选 ~20 s」混淆了 sim_07a 多进程**分摊**口径；实测**单例墙钟中位 101.7 s**
  （审计机，物理 15 s，Radau rtol 1e-6，常切线雅可比），最大 197.7 s。
- 由此裁定：**E1 薄切片（72 例）走路线 A 全量 ANCF**（4 进程批处理，预估 ~31 min）；代理模型推迟至
  E2/G2（1152×2 网格，串行 ~65 h 不经济），启用需过留出集误差 <10% / Top-3 一致率 >90% / Kendall τ>0.9。
- **sol.success 隐患已按裁决落实**：`sim_07a.simulate` 内部 `assert sol.success`；E1 生产流水线捕获该
  异常并以 **rtol 1e-5 重试**，重试仍失败 → 标 `FLEX_SOLVER_FAIL`，**不得静默进表**（见 §4.3）。
- E1 本机实测：快速段（IK+碰撞+基座反应+捕获+推进剂）平均 20.5 s/例，ANCF 平均 48.6 s/例；
  72 例 4 进程总墙钟 **≈22 min**（126 s 冒烟 + 1210 s 主扫），与审计外推一致（本机单线程更快）。

## 3. E1 薄切片定义（72 工况）

| 维度 | 取值 | 说明 |
|---|---|---|
| 目标 | `target_debris_v0` @3°/s | tumble_axis=[1,0.15,0.4]/‖·‖（惯性系），周期 T=120 s |
| 抓取点（D 系） | P1=[0.66,0,0.95]、P2=[0,0.66,0.95]、P3=[0.66,0,−0.95] | JSON 喷管缘特征；杠杆臂=点−cg（cg=[0.00027,0,−0.07054]，质量预算 SSOT）|
| 抓取系 C | z_C=外法向（P1/P3:+X_T，P2:+Y_T），x_C=±Z_T 背离本体 | P1 与 E0 标称帧完全一致 |
| 捕获相位 | t_c ∈ {0, 30, 60, 90} s | 即 0°/90°/180°/270° 相位 |
| 接近速度 | v_app ∈ {0.005, 0.01, 0.02} m/s | |
| 任务约束 | pose_6d、approach_5d | |
| 固定项 | q0=零位、rigid_6dof、b601 堆、capture_point_S=[0.95,0,−0.10] | q0 零位注：joint2/3 上限恰为 0，裕度在 q_c 处评估 |

G0 基线 = 网格单元 (P1, t_c=0, v_app=0.01, pose_6d)，即 E0 标称场景由**同一评价器**跑出。
柔性段只对通过 IK+碰撞的工况运行（69/72 符合，全部实际运行）。

复现命令（可重跑再生一切表/图）：

```
python 30_simulation/sim_09_grasp_evaluator/src/e1_thin_slice.py --workers 4   # 断点续跑：逐例即时 append
python 30_simulation/sim_09_grasp_evaluator/src/e1_analysis.py                 # 全部表 + 图 + gate 判定 JSON
python 30_simulation/sim_09_grasp_evaluator/tests/run_all.py                   # t1..t8 锚定回归
```

## 4. E1 结果

数据：`30_simulation/sim_09_grasp_evaluator/results/e1_results_72cases.csv`（72 行 × 68 列：候选全输入 +
scenario_hash + 契约 21 结果字段 + 展平便查列 + flex 状态 + M_PCS + provenance）。

### 4.1 工况统计（72 例）

| 类别 | 数量 | 明细 |
|---|---|---|
| IK 可行 | 69/72 | — |
| **IK_FAIL（如实记录 INADMISSIBLE）** | 3 | P3_tc00_v{5,10,20}mm_pose_6d：P3 底缘帧在 t_c=0 的 6D 期望姿态不可达（E0 已知落位/腕部姿态限制，未挪期望）|
| IMPULSE_EXCEED（ω⁺>2.0°/s） | 45 | P1 全部 24 例（ω⁺=3.054–3.070）+ P3 可行 21 例（ω⁺=2.512–2.525）|
| **FLEX_SOLVER_FAIL（重试后仍失败）** | 2 | P3_tc30_v10mm_approach_5d、P3_tc60_v5mm_approach_5d（两例本已 IMPULSE_EXCEED，未损失可行解；rtol 1e-5 重试仍不收敛，E2 待查）|
| ANCF rtol 1e-5 重试成功 | 5 | P1_tc60_v20mm_5d、P2_tc90_v{5,20}mm_6d、P3_tc30_v20mm_5d、P3_tc60_v20mm_5d —— 审计裁决的重试路径在生产中被真实触发 |
| **admissible（全部硬约束通过）** | **24** | **P2 全部 24 例**（ω⁺=1.489–1.718，H=3.79–4.23 N·m·s，E_flex=1.3e-6–1.8e-4 J）|

失败码统计表：`30_simulation/sim_09_grasp_evaluator/tables/infeasible_cases.csv`。

### 4.2 物理图景（图 `30_simulation/sim_09_grasp_evaluator/figures/fig_e1_phase_map.png`）

- **抓取点主导 ω⁺**：P2（+Y 缘）杠杆几何相对自旋轴（≈0.9X+0.14Y+0.36Z）使刚化后合成体
  ω⁺ 减半（1.49–1.72 vs P1 的 3.05–3.07°/s）—— 这是唯一使 2.0°/s 预算可满足的抓取点。
- **t_c 对刚体指标近乎不参与**（预判的坑，如实报告）：const_omega 下整个场景随 ω̂ 刚性旋转，
  E0 落位策略又把抓取点站位固定在 S 系 —— ω⁺/H 随相位仅变化 ≤1%（3.055→3.067），Δθ_base
  几乎恒定 1.627–1.630°。相位仅通过「追捕器姿态-场景滚转」二阶耦合进入刚体指标。
- **但 t_c 强烈参与柔性指标**：dv/dw 在 S 系的方向随相位滚转，帆板法向激励分量变化,
  P2 的 E_flex 从 1.6e-4 J（t_c=0）降到 1.3e-6 J（t_c=90）—— **136 倍**；这使相位选择在
  G2 里真实可优化（Pareto 前沿覆盖全部 4 个相位）。
- v_app 增大 → J_t 平移分量与 E_flex 增大、ω⁺ 微增；v=0.02 全部被支配（前沿仅含 v∈{0.005,0.01}）。

### 4.3 G0 / G1 / G2 对比（表 `30_simulation/sim_09_grasp_evaluator/tables/g0_g1_g2_comparison.csv`）

选择规则：G1 = 桶内（相位×速度×模式）可达 + 最大 manipulability（√det(JJᵀ)，1e-12 舍入并列时
按点号字典序）；G2 = 桶内 admissible → 六指标 Pareto 第 1 层 → 代表取最大 M_PCS。

**关键结构性发现**：E0 落位策略把每个抓取点映射到 S 系**同一期望 EE 位姿**（q_c 逐位相同），
故 manipulability 在桶内三点间**完全并列**（0.006559590149…，13 位有效数字相同）——
几何判据在本切片**不可判别**，G1 退化为字典序（21/24 桶选 P1；3 个 t_c=90/pose_6d 桶因
1e-12 量级差异恰选 P2）。动力学差异（ω⁺ 减半）对几何判据完全不可见 —— 这正是 G2 存在的理由。

G0 桶（t_c=0, v=0.01, pose_6d）逐指标（完整 21 项见 CSV）：

| 指标（方向） | G0 = G1（P1） | G2（P2） | G2 vs G1 |
|---|---|---|---|
| ω⁺ [°/s]（min，约束 2.0） | 3.0551（**超budget 53%**） | 1.5671 | **−48.7%** |
| Δθ_base [deg]（min） | 1.6294 | 1.6294 | 0.0% |
| |J_t| [N·s]（min） | 0.3545 | 0.9869 | +178.4% |
| E_flex [J]（min，约束 1e-3） | 2.49e-5 | 1.56e-4 | +524.9% |
| H_RW [N·m·s]（min，约束 5.475） | 3.6471 | 3.9513 | +8.3% |
| m_prop [g]（min） | 36.46 | 39.50 | +8.3% |
| manipulability（max） | 0.0065596 | 0.0065596 | 0.000% |
| admissible | 否（IMPULSE_EXCEED） | **是** | — |
| **M_PCS**（max） | **−0.5275** | **+0.2165** | **+141.0%** |

M_PCS = min(1−H/H_max, 1−J_thr/J_max, 1−E_flex/E_max, 1−ω⁺/ω_max, 1−Δθ_b/θ_max)，阈值出处：

| 项 | 阈值 | 出处 |
|---|---|---|
| H_max | 5.475 N·m·s | `hard_constraints_v1.yaml` wheel_momentum_max_Nms（PLACEHOLDER，1.5×sim_08）|
| ω_max | 2.0 °/s | 同上 post_capture_rate_max_dps（sim_04 POST_CAP_BUDGET）|
| E_max | 1e-3 J | 同上 flexible_energy_max_J（PLACEHOLDER，~40×sim_07a 标称）|
| J_max | 32.21 N·s | **导出值** = H_max / lever(0.17 m)（sim_08 双推力器力偶臂；yaml 无独立条目）|
| θ_max | 20° | **yaml 无条目** —— 占位：sim_05 主线全程基座漂移 19.20° 取整（列入 UNVERIFIED）|

全局 Pareto 第 1 层（`30_simulation/sim_09_grasp_evaluator/tables/pareto_front.csv`）：16 例，**全部 P2**，
覆盖 4 个相位 × v∈{0.005,0.01} × 两种任务模式；全局最优 M_PCS = **P2_tc90_v5mm_approach_5d**
（M_PCS=+0.2555，ω⁺=1.489°/s，E_flex=1.3e-6 J，H=3.801 N·m·s）。
图：`fig_e1_pareto.png`（前沿三投影 + G1 选点高亮 + G0 基线）、`fig_e1_g1_vs_g2.png`（逐指标条形+相对%）。

## 5. 通过条件逐条判定

| # | 条件 | 判定 | 证据 |
|---|---|---|---|
| ① | 锚定 7/7 通过 | **PASS** | E1 开跑前复跑 t1–t7 全 PASS；E1 完成后 t1–t8 全 PASS（`anchor_report_e0.md` 重新生成，t8 三条 G0 锚残差 0.0e0）|
| ② | 可追溯（CSV 含 hash+provenance） | **PASS** | 72 行含全部输入字段 + 72 个唯一 scenario_hash（与确定性网格逐一匹配，t8 校验）+ solver_provenance（module+commit，wall_time 剔除）|
| ③ | 存在 G2 候选：≥2 主指标改善且其余恶化 ≤5%，**或** M_PCS 提升 ≥20% | **PASS（经 M_PCS 分支）** | 21/24 桶 M_PCS 提升 ≥20%（G0 桶 −0.528→+0.216，+141%；不足 20% 的 3 桶是 G1 恰好也选中 P2）。**A 分支 0/24 桶满足**，如实说明：ω⁺ 减半的代价是 |J_t|+178%、E_flex 数倍（仍深居预算内）——杠杆几何权衡使六指标无一候选同时改善 ≥2 项且其余 ≤5%；这是物理权衡而非评价器缺陷（诊断清单核查：候选差异足够大 ✓、场景有挑战 ✓ [P1/P3 全部超 ω⁺ 预算]、t_c 经柔性通道真实参与 ✓ [E_flex 136×]、IK 多解保留 ✓ [每例 5–9 解]、归一化基于 yaml 阈值 ✓）|
| ④ | 图表自动生成 | **PASS** | 3 图 3 表全部由 `e1_analysis.py` 从结果 CSV 再生（重跑命令见 §3）；无手绘/硬编码数字 |
| ⑤ | 无未验证接触量 | **PASS** | 全程无接触力/抓取概率/阻抗最优值；`impact_severity_proxy` 在契约与表格中均显式标注 PROXY（|J_t|+|L_g|/lever 组合，非接触力）|

## 6. UNVERIFIED 清单

1. **θ_max=20°** 非 yaml 条目（基座姿态漂移无 GNC 指标来源），取 sim_05 主线 19.20° 取整的占位值；
   M_PCS 的 θ 项在本切片从不 binding（Δθ≈1.63°），不影响排序结论。
2. yaml 中 4 项阈值本身即 PLACEHOLDER（碰撞 0.02 m、条件数 1e4、H_max 5.475、E_max 1e-3）。
3. E0 落位策略（抓取点站位于固定 capture_point_S、追捕器姿态保持）**构造性地**压制了刚体指标的
   相位依赖与几何判据的可判别性 —— G1/G2 的对比结论依赖该策略；E2 若引入落位滚转自由度/
   相对姿态场景族，几何指标可能重新参与。
4. ANCF 单帆板(+Y)、单向耦合（基座速度跳变→帆板，无反馈）、nominal EI 单刚度；
   2 例 FLEX_SOLVER_FAIL（P3/approach_5d/v10&v5）在 rtol 1e-5 下仍不收敛，根因未查明（E2 项）。
5. 碰撞几何 v1 粗糙（胶囊+图元、A6 不查服务星-目标本体接近）；接近轨迹为关节空间 min-jerk
   （非笛卡尔跟踪），碰撞裕度沿该轨迹评估。
6. const_omega 传播（惯性固定自旋轴假设）；torque_free 通道已具备但本切片未启用。
7. m_prop 与 J_thr 与 H_RW 线性相关（sim_08 代数式），六指标实际独立维度为 4。

## 7. 是否建议进入 E2

**建议进入**：评价器在 72 例上零手工干预地复现了「几何判据不可判别、动力学判据把不可行基线
（ω⁺ 超预算 53%）翻转为 +25.6% 裕度候选」的完整证据链，且锚定/确定性/追溯三件套全绿 ——
E2 的前提（可信的单例评价器 + 实测成本模型）已就绪；E2 应优先解决落位滚转自由度、
代理模型门控（1152×2 网格）与 FLEX_SOLVER_FAIL 根因三件事。

---

### 附：M_PCS 最优候选描述

> P2 喷管缘抓取点（P2_tc90_v5mm_approach_5d）虽然几何可操作度并不更优（与 G1 选点相差
> 0.000%，落位策略下几何指标不可判别），但确定性工况下抓取后仍保留 **25.6%** 系统级稳定裕度
> （M_PCS=+0.256，binding 项为 ω⁺ 裕度：1.489/2.0 °/s），而几何选点 P1 的系统裕度为
> **−53.3%**（ω⁺=3.067 °/s，超出捕获后角速率预算）。

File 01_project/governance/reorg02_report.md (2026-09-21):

# REORG-02 项目目录归一与安全迁移报告

- 日期：2026-07-22
- 基线分支：`feat/sim09-grasp-evaluator`
- 基线提交：`b4dd48aa728876ee15636bd03d4f6734dad7b54b`
- 执行分支：`codex/reorg-02-project-layout`

## 1. 裁决

`REORG02_COMPLETE_WITH_PATH_LOCKED_EXCEPTIONS`

项目已经建立唯一根导航、目录所有权、命名规则、受控资料收件箱和迁移记录。无 Gate 绑定的散落资产已迁入对应领域；会迫使改写机器 Gate、冻结 manifest 或科学结果的旧路径保持原位，并作为竞争期路径锁定例外登记。

## 2. 执行边界

- 未运行新仿真、VLA、装配实验或科学 Gate。
- 未修改任何科学数值、verdict、阈值或结果表。
- 文件内容只允许目录导航、路径引用和迁移审计所必需的变化。
- 迁移前已在工作区外备份全部 71 个未跟踪文件，并生成 795 文件 SHA-256 清单。
- 恢复备份：`C:\Users\stude\AppData\Local\Temp\codex_reorg02_b4dd48a_20260722_162640`。

## 3. 实际迁移

共迁移 11 个文件：

- 7 份架构文件：`research/project_architecture_final/` → `research/00_project_architecture/`。
- 文献种子笔记：根目录 → `docs/00_references/source_notes/`。
- `建议.docx`：根目录 → `docs/95_inbox/source_documents/`。
- 自由漂浮服务星 Stage 1 占位说明：`sim/` → Stage 1 `07_next_actions/`。
- 几何审计裁决：独立 `docs/geometry/` → Stage 1 `06_reviews/`。

完整逐文件映射见 [`reorg02_migration_manifest.csv`](./reorg02_migration_manifest.csv)。

## 4. 路径锁定例外

以下资产不做物理搬迁：

- `e15_core_coverage/`、`e15_ancf_certification/`、`e16_sync_capture/`。
- 根目录 sim_09 的 `src/tests/results/figures/tables` 分片。
- `research_integration/`。
- `research/competition_convergence/` 与 `artifacts/competition_convergence/`。
- `30_simulation/asm_00_interface_preflight/`。
- 根目录 `空间机械臂.docx`。

原因不是权限不足，而是这些路径已经写入科学 Gate、测试常量、哈希清单或比赛证据合同。物理改名会改变证据本体，超出“只整理、不改结果”的边界。
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

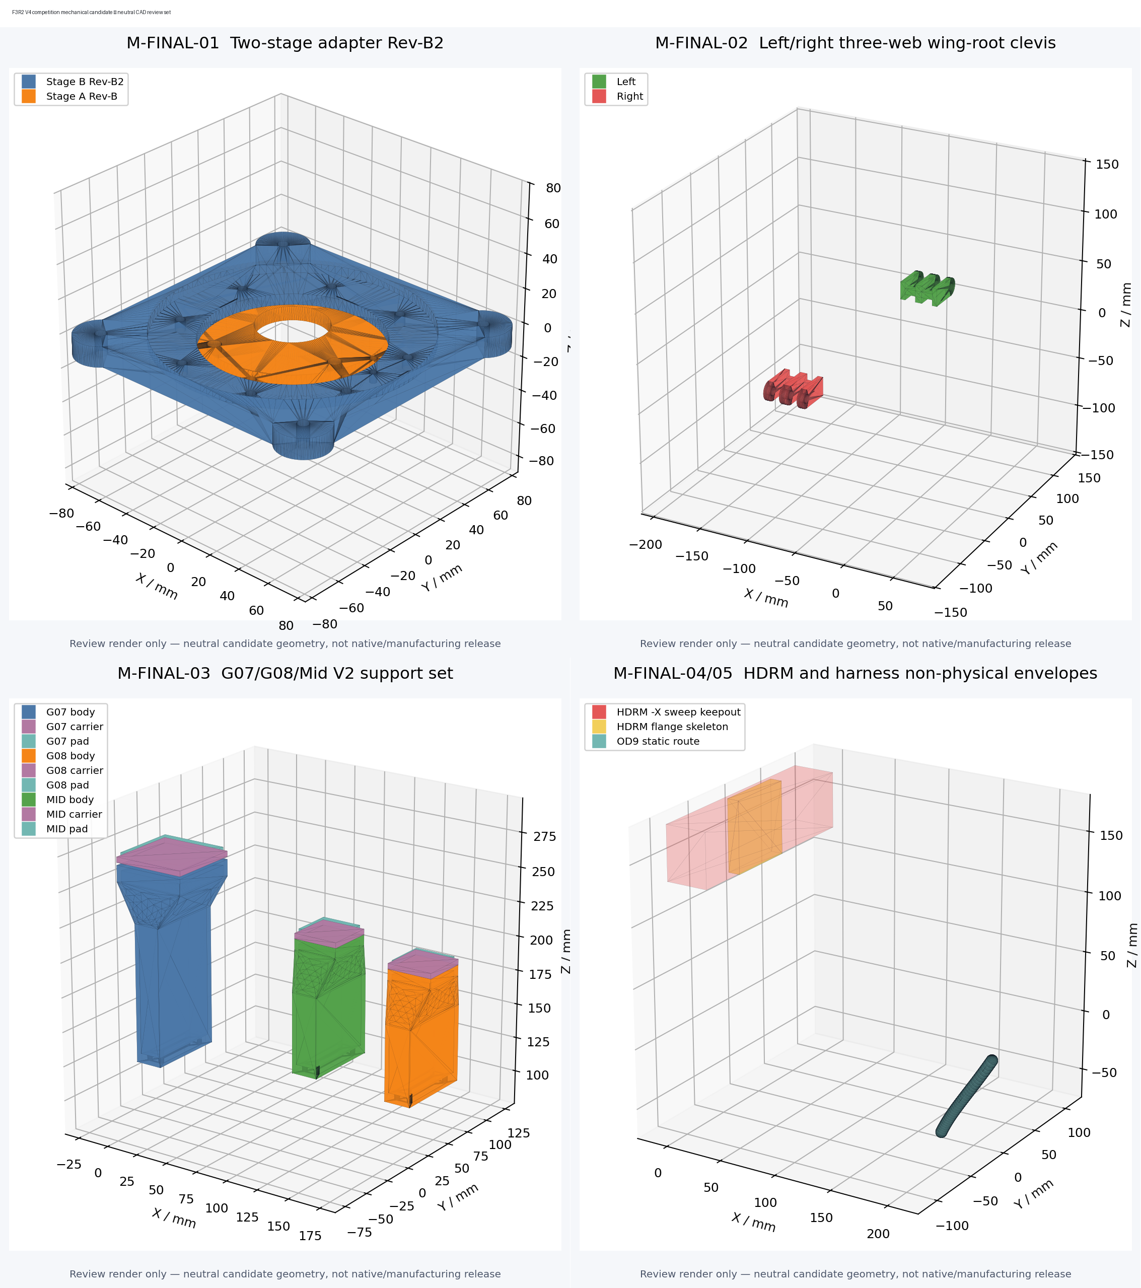
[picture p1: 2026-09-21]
20_engineering/F3R2_V4_COMPETITION_MECHANICAL_CANDIDATE_20260809/10_validation/renders/MFINAL_MECHANICAL_CANDIDATE_REVIEW_COLLAGE.png

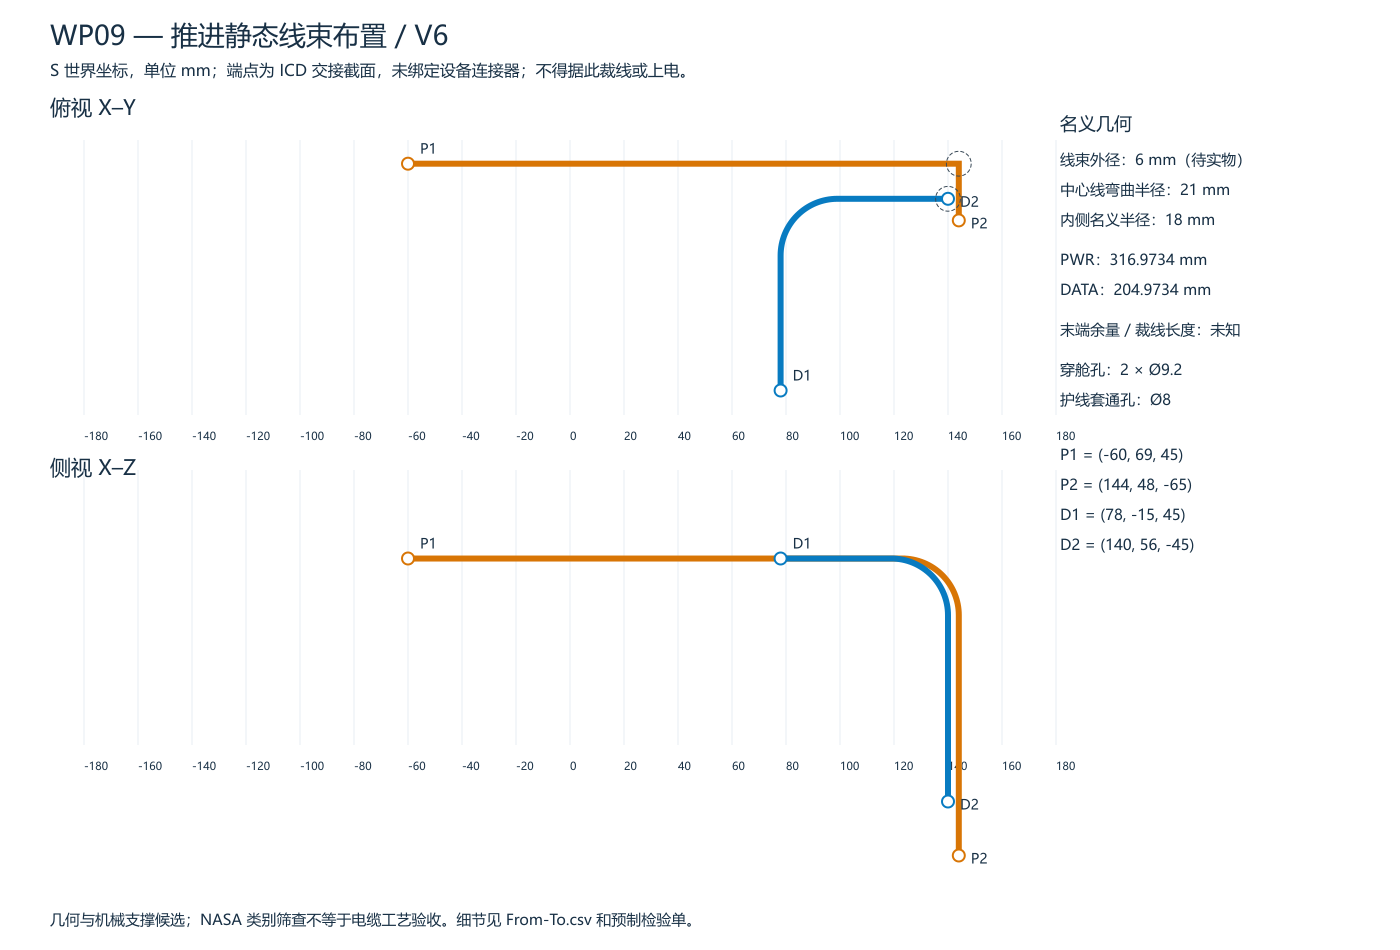
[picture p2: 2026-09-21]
01_project/competition/SERVICE_ROBOT_MECHANICAL_CONSOLIDATION_20260905/runs/wp09_interfaces_20260907_1525/docs/HARNESS_LAYOUT_S_WORLD.png

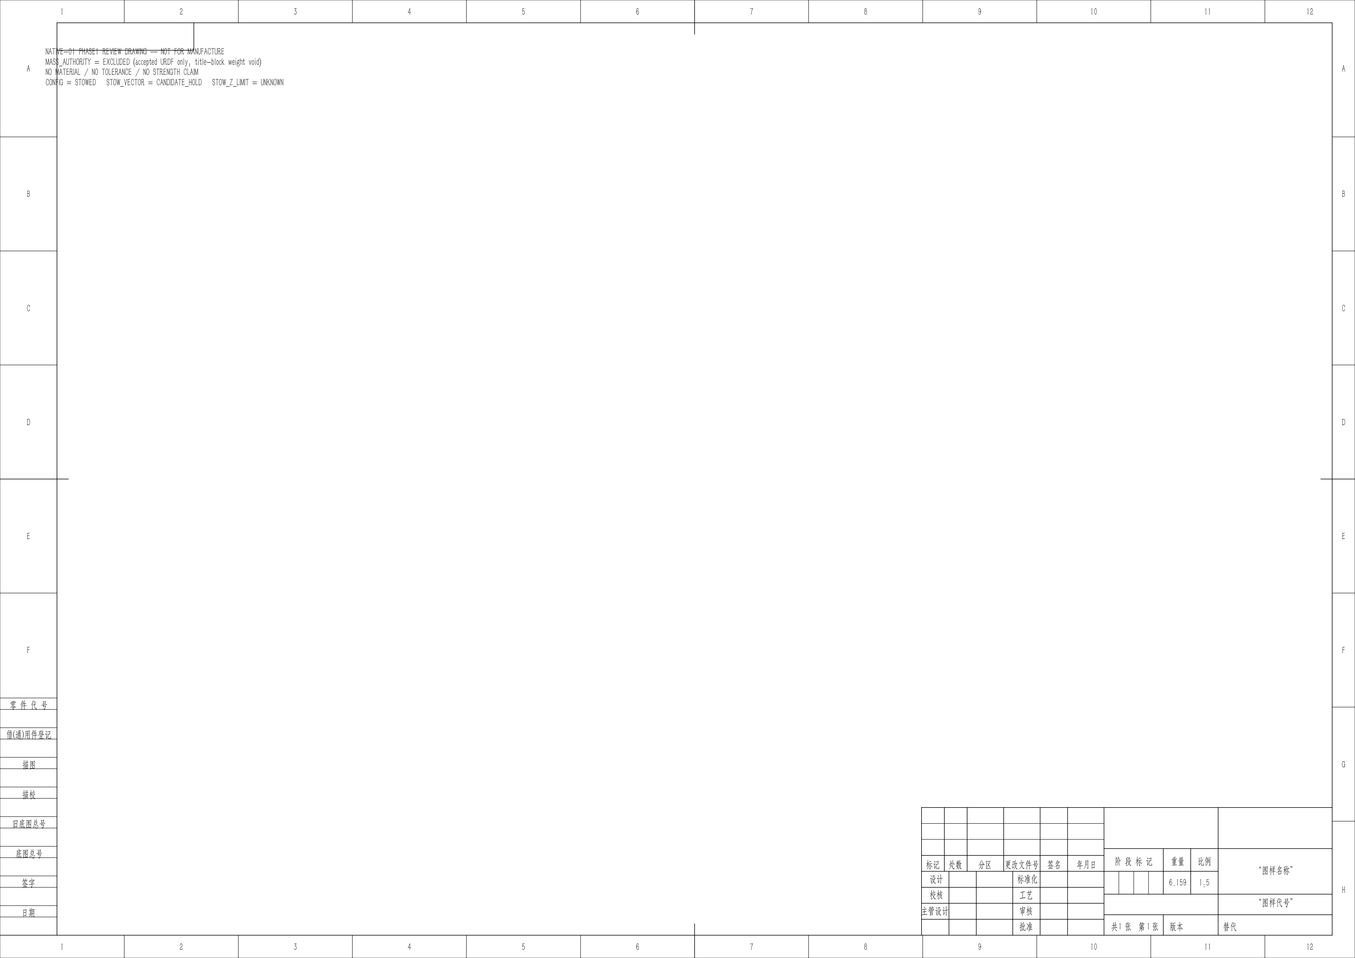
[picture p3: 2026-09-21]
10_research/mechanical_design_progress_gallery_20260729/assets/drawing_stowed_page1.png

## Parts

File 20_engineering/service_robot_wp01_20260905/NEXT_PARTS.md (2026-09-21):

# WP01 之后立即执行的首批零件化

日期：2026-09-05。父装配：`WP01_ROOF_EXTERNAL_R1`。本清单沿用本轮用户开始进一步设计的指令，工作顺序由真实接口依赖决定。设计参数见 [design_parameters.json](design_parameters.json)，对偶要求见 [interface_requirements.csv](interface_requirements.csv)，试装步骤见 [ASSEMBLY_AND_TEST_PLAN.md](ASSEMBLY_AND_TEST_PLAN.md)。

**第一批要交付一个可装、可调、可保持并释放的组合件：框架段＋根部承载板/纵梁连接＋B601＋两鞍座＋保持释放＋真实线束。** 当前的外廊、支承和机构几何提供设计位置；下面的零件化任务将这些位置落实为材料、对偶面、定位、紧固、接触和动作。

当前根部 frame 保持 x=90 mm、y=0 mm、z=125.15 mm，旋转 I；名义 BRep 基座局部承载底面为 z=2.405 mm，因此真实几何接触面在全局 z=127.555 mm。依据为 [接口几何收据](results/INTERFACE_GEOMETRY.json) 的同原点对偶情况，不再将 root frame 与承载面混同。accepted STL 基座 bbox 从局部 z=0 起，与名义 BRep 不同，首件必须完成两类模型及实物的基准注册。

母线核心是 366×226.3×226.3 mm。本方案外置臂使整体较高，当前不以紧凑标准 12U 包络合规作为已经完成的结果。姿态和包络变化的最终值以 [布局比较](LAYOUT_COMPARISON.md) 与 [结果目录](results/) 为准。

## 首批组合件与具体零件

本轮新增了一个可并行处理的输入修复任务：重建base_link与link2内共6个无效源实体拓扑。默认ShapeFix保形修复未奏效，记录见 `results/SOURCE_TOPOLOGY_REPAIR_PROBE.json`。保留实测/供应商外形与接口，修复后逐实体验证、核对体积和基准，再替换候选输入；不得删除这些实体以通过校验。

| 优先顺序 / 零件号前缀 | 必须设计的零件/对偶 | 输入与尺寸必须明确 | 完成检查及交付 |
|---|---|---|---|
| 1 / WP01-RB | 根部承载板、局部加劲/角撑、与两侧纵梁连接的锚固件 | B601/M3R 真实孔基准；根部 6 分量载荷、刚度目标；框梁截面/材料；螺纹深度/预紧/工具方向 | 从臂根经实体与紧固件到纵梁的载荷通路；公差、滑移和挠度分析；根部安装试片与可制造图 |
| 2 / WP01-MT | M3R A/B 对偶细化、定位件与紧固件 | A 环/B 槽嵌套；孔型/底面/止口/实际装配面；工艺公差与接触区域；BRep/STL/实物注册 | A/B/base_link 共原点 z125.15，承载接触面 z127.555；按真实对偶判断接触，不能把 base_link 再抬高 2.405 mm；装入和扳手试装 |
| 3 / WP01-SA | 鞍座 A 底座、可调承托、可换接触垫与紧固件 | 支承点对应的实际 link 和允许承载壳体区域；垫材料/厚度；调整范围；接触面压 | 支承设置间隙通过垫片/调节闭合；量测实际接触分布与装后位置；不压电缆、电机接口或活动关节 |
| 4 / WP01-SB | 鞍座 B 底座、可调承托、可换接触垫；必要的浮动/限位件 | 与 A、根部及保持器共同的约束自由度；公差/温变/壳体挠曲；承载分流 | 避免无法调节的过约束；真实接触与释放退出均成立；给出每个支承的载荷和允许调整量 |
| 5 / WP01-HR | 臂侧保持对偶件、锁扣、硬止挡、预紧调节件、可复位释放支架 | 保持载荷和预紧；释放执行器型号/力/行程；退出方向；手动复位空间 | 保持状态由实际接触承载；锁扣完全退出初始展臂和线束区域；记录释放反力/行程/时间及拒动状态 |
| 6 / WP01-HS | 释放确认传感器支架、触发目标件、接线固定件 | 传感器型式/触发范围/误差；完全脱开与半脱开的位置差 | 状态信号对应真实机械脱开；半脱开、断线与卡滞试验；支架可调整和复检 |
| 7 / WP01-HB | 母线至臂根的固定线夹、连接器安装板、穿舱/防磨件、根部过渡导向件 | 真正的电缆/护套/接头/背壳尺寸；插拔与锁紧工具空间；动态弯曲和应力释放数据 | 用真实样段验证同一固定点下的保持→释放→初动；连接器不承担非设计拉力；保留独立拆臂路径 |
| 8 / WP01-HJ | 各关节活动段线夹、导向件和腕部服务环支架 | 每段附属 link；外径、余长、动态弯曲、扭转/循环和摩擦限制 | 从单关节到组合路径测曲率/扭转/反力；不以静态管线外形证明活动线束全程可用 |
| 9 / WP01-FT | 腕部至 F/T 转接件、F/T 至夹爪转接件、定位件/紧固件 | 实选 F/T 厚度、孔型、载荷、质量/惯量、过载保护、连接器；夹爪掌/指真实几何 | **在腕部和夹爪之间插入 F/T 后重建腕链/TCP**；同步更新碰撞/质量/动力学及收拢/支承关系；重新检查全部相关姿态 |
| 10 / WP01-CM | 末端相机支架、线夹与可重复定位基准 | 实选相机/镜头尺寸、视场/工作距离、外参误差目标与靶标位置 | 视场覆盖接近/抓持；工具和手指不遮挡关键区域；支持标定、单独更换及外参恢复 |
| 11 / WP01-WL/WR | 左右翼根支架、铰链轴/轴套或实选铰链对偶、止挡/锁止、翼保持件 | 实选翼结构/质量/惯量；展开力矩、驱动/弹簧和阻尼；轴向间隙/预紧/润滑；服务环 | 翼根框架受力、保持/释放/锁止、臂翼联合序列和带真实线束部署；每侧都有独立装配和拆卸路径 |
| 12 / WP01-AT | 电池/电源/计算机/臂驱动/姿控设备安装板、导轨、支架与热连接件 | 实选设备含连接器包络、孔/底脚、功耗和散热面；插头/工具/抽出空间 | 设备可沿规定路径装入拆出；导轨/紧固/热垫/线束同时成立；不要把预算盒体当已采购设备 |
| 13 / WP01-GSE | 框架/机械臂托持工装、接触/释放测试工装和必要卸载点 | 总体/分总成重心、试验载荷、卸载误差、仪器及调节范围 | 工装通过自身载荷和稳定性核查；释放与低速动作不由电缆或薄壳支承；试验条件可记录和复现 |

本表为首批零件号前缀和任务划分，不能据此直接形成采购数量。一个前缀下可有多件；详细实体拆分后分配唯一零件号、数量、版本与制造/采购属性。

## 两项必须在零件化时纠正的几何语义

**把 2 mm 支承设置间隙闭合成真实接触。** 当前 `support_mesh_clearance_mm=2` 表示几何初案对源网格设置了间隔。承载鞍座需要确定接触面法向、垫片压缩/刚度、调节量、允许壳体面压和预紧，才能形成可计算的反力。不能一面保留空气间隙，一面在受力图中画出持续支承力；也不能简单加厚垫片后跳过过约束和释放检查。先设计调整结构，再按组合件的实际接触校正模型。

**F/T 是腕链中的真实机械层。** 实选 F/T 放入腕部与夹爪之间会改变腕部长度、质量、TCP 和线束位置。需保留 B601 基础链来源，同时派生包含传感器/两侧转接的本候选工具链；更新 `T_WRIST_FT`、`T_FT_TOOL`、TCP、惯量和碰撞几何，重查收拢/支承、夹爪全行程和工作区。传感器外形靠近原夹爪的示意摆放只表示预留位置。

## 输入补齐与并行安排

1. **总体/根部负责人先完成 WP01-RB/MT 的实配接口。** 实物量测根部孔、物理安装面、连接器位置及壳体可支承区域；材料、载荷和紧固输入同步登记。未知量保持 `TBD` 并列出获取方法，可以先做可调整候选，不能填任意数后声明承载完成。
2. **机构与线束负责人共同做 WP01-SA/SB/HR/HS/HB。** 锁扣、鞍座和线束不能分别固定位置后再相互适配。用最终检验过的收拢姿态，联合选择接触点、释放退出方向、连接器及线夹，并输出组合件图。
3. **末端负责人并行实选 F/T/相机并完成 WP01-FT/CM。** 先补厚度、孔型、线缆方向和载荷，再重建工具链；工具链修改会反馈根部载荷和收拢保持设计，必须在全星详细出图前合入。
4. **翼与航电负责人并行做 WP01-WL/WR/AT。** 共用同一主框架和运动空间；设备实际尺寸取代预算盒后更新质量账本，翼设计同时包含铰链、保持/锁止和根部线束。
5. **试装负责人做 WP01-GSE 和首件装配。** 先记录孔位、接触、工具、插拔和释放问题；依据实测改件，再进行明确载荷和循环条件的试验。

## 每个组合件的完成条件

完成的组合件应具备可编辑原生零件/总装、同修订 STEP、带公差和基准的关键尺寸图、材料/工艺/标准件表、逐件质量来源、装配顺序和测量方案。每个对偶界面须能回答“靠什么定位、怎样紧固、怎样传力、怎样拆卸”，每个活动界面须能回答“怎样释放、怎样确认、怎样避让线束、失电后在哪里”。

首件验证由易到难推进：接口量测与试插 → 无载装配 → 接触/预紧调节 → 释放和初动 → 真实线束全路径 → 规定载荷/循环 → 回写整星总装。实际验证等级、数值和结论随记录给出，不由模型导出或清单勾选自动产生。

## 方法参照

NASA 服务机械臂资料将活动线束与末端 F/T 作为系统组成，并介绍工程设计样机先行验证的做法。本包将其作为联合样件和末端接口工作的参考，不引用其任务能力作为 B601 的能力。[NASA Robotic Servicing Arm](https://www.nasa.gov/isam/robotic-servicing-arm/)

机构需求、设计说明、分析验证及使用/复位说明可参照 ECSS-E-ST-33-01C Rev.2 官方列出的文档结构，逐步落实到本表的保持释放和翼铰链件。标准条文符合性需要适用性裁剪和逐项证据，本清单不作标准认证声明。[ECSS-E-ST-33-01C Rev.2 — Mechanisms](https://ecss.nl/standard/ecss-e-st-33-01c-rev-2-1-march-2019-space-engineering-mechanisms/)

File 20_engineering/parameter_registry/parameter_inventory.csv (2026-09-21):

parameter_id | value | unit | role | status | verification_status | source_path | source_locator | consumers | modifiable_now | unlock_trigger | notes
servicer_bus_mass_no_panels | 23.3032134 | kg | model_anchor | FROZEN_MODEL_ANCHOR | MACHINE_RECOMPOSITION_PASS | 20_engineering/config/geometry/service_spacecraft_v1.yaml | rigid_bus_no_panels.mass_kg | sim07;sim11;e16 | false | new_mass_budget_contract | 24 kg whole model minus two panel shares; model closure is not flight measurement
servicer_whole_sat_reference_mass | 24.0 | kg | model_anchor | FROZEN_MODEL_ANCHOR | MASS_BUDGET_BOUND | 20_engineering/config/geometry/service_spacecraft_v1.yaml | whole_sat_reference.mass_kg | sim01..sim06;sim08;sim10 | false | new_mass_budget_contract | rigid-body reference mass
b601_total_dynamics_mass | 4.6956 | kg | hardware_model | PROVISIONAL | MEDIUM_CONFIDENCE | 20_engineering/config/geometry/arm_b601_v1.yaml | mass_properties.total_dynamics_mass_kg | sim05;sim09;sim11;e16 | false | physical_weighing_of_real_arm | hybrid evidence-ranked mass; pending physical weighing
target_satellite_mass | 22.0 | kg | target_model | LOW_CONFIDENCE | LOW_RA003_NEVER_MEASURED | 20_engineering/config/geometry/target_models_v1.yaml | target_satellite_v0.mass_kg | sim06;sim10;sim12 | false | traceable_target_mass_and_inertia | current satellite target model
target_debris_mass | 150.0 | kg | target_model | LOW_CONFIDENCE | LOW_RA003 | 20_engineering/config/geometry/target_models_v1.yaml | target_debris_v0.mass_kg | sim06;sim08;sim10;sim11;sim12;e16 | false | traceable_target_mass_and_inertia | placeholder debris model also has nonphysical density issue
panel_mass_each | 0.3483933 | kg | flexible_model | FROZEN_PLACEHOLDER_MODEL_ANCHOR | MASS_CLOSURE_PASS_NOT_PHYSICAL_VALIDATION | 20_engineering/config/geometry/flexible_appendage_v1.yaml | mass.m_panel_kg | sim07;sim11 | false | measured_or_CAD_FEA_panel_mass | uniform-density share; current two-panel mass closure is exact
panel_first_frequency_low | 0.7 | Hz | flexible_model | PROVISIONAL | DESIGN_ASSUMPTION | 20_engineering/config/geometry/flexible_appendage_v1.yaml | stiffness.cases.flexible_low.f1_hz | sim07;sim11 | false | measured_or_FEA_modal_data | lower sensitivity-envelope anchor
panel_first_frequency_nominal | 1.0 | Hz | flexible_model | PROVISIONAL | DESIGN_ASSUMPTION | 20_engineering/config/geometry/flexible_appendage_v1.yaml | stiffness.cases.nominal.f1_hz | sim07;sim11 | false | measured_or_FEA_modal_data | nominal first-mode assignment
panel_first_frequency_high | 1.3 | Hz | flexible_model | PROVISIONAL | DESIGN_ASSUMPTION | 20_engineering/config/geometry/flexible_appendage_v1.yaml | stiffness.cases.flexible_high.f1_hz | sim07;sim11 | false | measured_or_FEA_modal_data | upper sensitivity-envelope anchor
panel_modal_damping_geometry_card | 0.01 | dimensionless | flexible_model | PROVISIONAL | TBD_CITE_LITERATURE | 20_engineering/config/geometry/flexible_appendage_v1.yaml | damping.zeta | sim07 and geometry-level references | false | traceable_literature_or_measurement | do not merge with sim11 zeta without resolving ownership
sim11_modal_count_each_panel | 3 | count | flexible_model | PROVISIONAL | GATE_LISTED_PROVISIONAL | 20_engineering/config/coupled_scene/coupled_model_v0.yaml | panels.n_modes | sim11 | false | new_convergence_contract_with_physical_modes | current default; Gate uses forward refinement
sim11_modal_damping | 0.005 | dimensionless | flexible_model | PROVISIONAL | GATE_LISTED_PROVISIONAL | 20_engineering/config/coupled_scene/coupled_model_v0.yaml | panels.zeta_modal | sim11 | false | traceable_literature_or_measurement | distinct from geometry-card 0.01 value
sim11_contact_duration_nominal | 20.0 | ms | contact_model | PROVISIONAL | PENDING_B601_MEASUREMENT | 20_engineering/config/coupled_scene/scene_A2_capture.yaml | contact.T_c_ms_nominal | sim11 | false | measure_B601_gripper_contact_duration | finite-bandwidth nominal value
sim11_contact_duration_sweep | 5|10|20|50|100 | ms | contact_model | PROVISIONAL | DESIGN_SWEEP | 20_engineering/config/coupled_scene/scene_A2_capture.yaml | contact.T_c_ms_sweep | sim11 | false | pre_register_new_contact_bandwidth_study | sensitivity grid; not probability distribution
post_capture_rate_limit | 2.0 | deg/s | mission_gate | MISSION_ASSUMPTION | PARTIAL | 30_simulation/e15_core_coverage/config/threshold_registry_core_v1.yaml | thresholds.post_capture_rate_max_dps | sim09;sim10;sim12;e15;e16 | false | traceable_mission_requirement | current primary binding threshold in several negative cases
base_attitude_change_limit | 20.0 | deg | mission_gate | PROVISIONAL | UNVERIFIED | 30_simulation/e15_core_coverage/config/threshold_registry_core_v1.yaml | thresholds.base_attitude_change_max_deg | sim09;e15;e16 | false | traceable_attitude_requirement | thin-slice source
collision_margin_min | 0.02 | m | mission_gate | PROVISIONAL | UNVERIFIED | 30_simulation/e15_core_coverage/config/threshold_registry_core_v1.yaml | thresholds.collision_margin_min_m | sim09;e15;e16 | false | geometry_and_safety_requirement_review | minimum relation
joint_limit_margin_min | 0.05 | rad | mission_gate | PROVISIONAL | UNVERIFIED | 30_simulation/e15_core_coverage/config/threshold_registry_core_v1.yaml | thresholds.joint_limit_margin_min_rad | sim09;e15;e16 | false | hardware_joint_limit_validation | minimum relation
condition_number_max | 10000.0 | dimensionless | mission_gate | PROVISIONAL | UNVERIFIED | 30_simulation/e15_core_coverage/config/threshold_registry_core_v1.yaml | thresholds.condition_number_max | sim09;e15;e16 | false | kinematic_conditioning_requirement_review | maximum relation
flexible_energy_limit | 0.001 | J | mission_gate | PROVISIONAL | UNVERIFIED | 30_simulation/e15_core_coverage/config/threshold_registry_core_v1.yaml | thresholds.flexible_energy_max_J | e15;e16 policy | false | define_physical_damage_or_stability_basis | not active in sim10 or sim12 formal criteria
strategy_wheel_capacity_small | 0.045 | N*m*s | actuator_tier | PROVISIONAL | PLACEHOLDER_CLASS | 20_engineering/config/mission_feasibility/scan_v0.yaml | actuator_tiers.wheel_capacity_Nms.wheels_small | sim10;sim12 | false | select_COTS_hardware | three-small-wheel class assumption
strategy_wheel_capacity_large | 0.300 | N*m*s | actuator_tier | PROVISIONAL | PLACEHOLDER_CLASS | 20_engineering/config/mission_feasibility/scan_v0.yaml | actuator_tiers.wheel_capacity_Nms.wheels_large | sim10;sim12 | false | select_COTS_hardware | default strategy tier; not the e15 5.475 Nms gate
e15_wheel_momentum_gate | 5.475 | N*m*s | mission_gate | PROVISIONAL | UNVERIFIED | 30_simulation/e15_core_coverage/config/threshold_registry_core_v1.yaml | thresholds.wheel_momentum_max_Nms | e15;e16 | false | traceable_actuator_and_requirement_basis | different contract role from sim10 0.300 Nms tier
default_thruster_force | 0.1 | N | actuator_tier | PROVISIONAL | PLACEHOLDER_CLASS | 20_engineering/config/mission_feasibility/scan_v0.yaml | actuator_tiers.thruster_force_N | sim10;sim12 | false | select_and_verify_thruster | sim08 middle class
default_thruster_lever | 0.17 | m | actuator_tier | PROVISIONAL | MODEL_ASSUMPTION | 20_engineering/config/mission_feasibility/scan_v0.yaml | actuator_tiers.default_tier.lever_m | sim10;sim12;e15;e16 | false | freeze_CAD_thruster_layout | also a root for derived impulse limit
cold_gas_specific_impulse | 60.0 | s | actuator_tier | PROVISIONAL | UNVERIFIED | 30_simulation/e15_core_coverage/config/threshold_registry_core_v1.yaml | actuator_model.isp_s | sim08;sim10;sim12;e15;e16 | false | select_and_verify_thruster | root for derived propellant budget
thruster_total_impulse_limit | 32.205882352941174 | N*s | derived_budget | DERIVED | UNVERIFIED_ROOTS | 30_simulation/e15_core_coverage/config/threshold_registry_core_v1.yaml | thresholds.thruster_impulse_max_Ns | e15;e16 | false | validate_wheel_gate_and_thruster_lever | algebraically wheel_momentum_gate divided by lever; not independent
propellant_budget_max | 54.73476731425644 | g | derived_budget | DERIVED | UNVERIFIED_ROOTS | 30_simulation/e15_core_coverage/config/threshold_registry_core_v1.yaml | thresholds.propellant_budget_max_g | sim10;sim12;e15;e16 | false | validate_impulse_Isp_and_g0_roots | not an independent root metric
detumble_time_max | 3600.0 | s | mission_gate | MISSION_ASSUMPTION | PROVISIONAL | 20_engineering/config/mission_feasibility/scan_v0.yaml | gates.t_detumble_max_s | sim10;sim12 | false | traceable_mission_timeline_requirement | upper task-time assumption

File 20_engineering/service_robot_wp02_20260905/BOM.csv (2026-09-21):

part_number | quantity | classification | geometry_basis | part_STEP | manufacturing_status
WP01-RB-LONGERON-R2 | 4 | ONBOARD_HARDWARE_CANDIDATE | NEW_PARAMETRIC_CANDIDATE | parts/WP01-RB-LONGERON-R2.step | NOT_FOR_MANUFACTURE
WP01-RB-END-FRAME-R2 | 2 | ONBOARD_HARDWARE_CANDIDATE | NEW_PARAMETRIC_CANDIDATE | parts/WP01-RB-END-FRAME-R2.step | NOT_FOR_MANUFACTURE
WP01-RB-END-PLUG-R2 | 8 | ONBOARD_HARDWARE_CANDIDATE | NEW_PARAMETRIC_CANDIDATE | parts/WP01-RB-END-PLUG-R2.step | NOT_FOR_MANUFACTURE
WP01-MT-M4X22-ENVELOPE | 8 | STANDARD_HARDWARE_GEOMETRY_CANDIDATE | NEW_PARAMETRIC_CANDIDATE | INPUT_STEP_OR_ASSEMBLY_ENVELOPE | NOT_FOR_MANUFACTURE
WP01-RB-BRIDGE-R2 | 1 | ONBOARD_HARDWARE_CANDIDATE | NEW_PARAMETRIC_CANDIDATE | parts/WP01-RB-BRIDGE-R2.step | NOT_FOR_MANUFACTURE
WP01-RB-UPPER-BEAM-R2 | 2 | ONBOARD_HARDWARE_CANDIDATE | NEW_PARAMETRIC_CANDIDATE | parts/WP01-RB-UPPER-BEAM-R2.step | NOT_FOR_MANUFACTURE
WP01-RB-LOWER-BEAM-R2 | 2 | ONBOARD_HARDWARE_CANDIDATE | NEW_PARAMETRIC_CANDIDATE | parts/WP01-RB-LOWER-BEAM-R2.step | NOT_FOR_MANUFACTURE
WP01-RB-PILLAR-R2 | 4 | ONBOARD_HARDWARE_CANDIDATE | NEW_PARAMETRIC_CANDIDATE | parts/WP01-RB-PILLAR-R2.step | NOT_FOR_MANUFACTURE
WP01-RB-PILLAR-PLUG-R2 | 8 | ONBOARD_HARDWARE_CANDIDATE | NEW_PARAMETRIC_CANDIDATE | parts/WP01-RB-PILLAR-PLUG-R2.step | NOT_FOR_MANUFACTURE
WP01-RB-LOWER-SPACER-R2 | 4 | ONBOARD_HARDWARE_CANDIDATE | NEW_PARAMETRIC_CANDIDATE | parts/WP01-RB-LOWER-SPACER-R2.step | NOT_FOR_MANUFACTURE
WP01-MT-M4-TIEROD228-ENVELOPE | 4 | STANDARD_HARDWARE_GEOMETRY_CANDIDATE | NEW_PARAMETRIC_CANDIDATE | INPUT_STEP_OR_ASSEMBLY_ENVELOPE | NOT_FOR_MANUFACTURE
WP01-MT-WASHER4-ENVELOPE | 8 | STANDARD_HARDWARE_GEOMETRY_CANDIDATE | NEW_PARAMETRIC_CANDIDATE | INPUT_STEP_OR_ASSEMBLY_ENVELOPE | NOT_FOR_MANUFACTURE
WP01-MT-NUT4-ENVELOPE | 4 | STANDARD_HARDWARE_GEOMETRY_CANDIDATE | NEW_PARAMETRIC_CANDIDATE | INPUT_STEP_OR_ASSEMBLY_ENVELOPE | NOT_FOR_MANUFACTURE
WP01-MT-M3RA-REUSED | 1 | ONBOARD_HARDWARE_CANDIDATE | UNCHANGED_IMPORTED_NOMINAL_BREP | INPUT_STEP_OR_ASSEMBLY_ENVELOPE | NOT_FOR_MANUFACTURE
WP01-MT-M3RB-REUSED | 1 | ONBOARD_HARDWARE_CANDIDATE | UNCHANGED_IMPORTED_NOMINAL_BREP | INPUT_STEP_OR_ASSEMBLY_ENVELOPE | NOT_FOR_MANUFACTURE
WP01-MT-WASHER6-ENVELOPE | 8 | STANDARD_HARDWARE_GEOMETRY_CANDIDATE | NEW_PARAMETRIC_CANDIDATE | INPUT_STEP_OR_ASSEMBLY_ENVELOPE | NOT_FOR_MANUFACTURE
WP01-MT-M6X40-ENVELOPE | 4 | STANDARD_HARDWARE_GEOMETRY_CANDIDATE | NEW_PARAMETRIC_CANDIDATE | INPUT_STEP_OR_ASSEMBLY_ENVELOPE | NOT_FOR_MANUFACTURE
WP01-MT-NUT6-ENVELOPE | 4 | STANDARD_HARDWARE_GEOMETRY_CANDIDATE | NEW_PARAMETRIC_CANDIDATE | INPUT_STEP_OR_ASSEMBLY_ENVELOPE | NOT_FOR_MANUFACTURE
WP01-MT-M5X25-ENVELOPE | 8 | STANDARD_HARDWARE_GEOMETRY_CANDIDATE | NEW_PARAMETRIC_CANDIDATE | INPUT_STEP_OR_ASSEMBLY_ENVELOPE | NOT_FOR_MANUFACTURE
WP01-MT-WASHER5-ENVELOPE | 16 | STANDARD_HARDWARE_GEOMETRY_CANDIDATE | NEW_PARAMETRIC_CANDIDATE | INPUT_STEP_OR_ASSEMBLY_ENVELOPE | NOT_FOR_MANUFACTURE
WP01-MT-NUT5-ENVELOPE | 8 | STANDARD_HARDWARE_GEOMETRY_CANDIDATE | NEW_PARAMETRIC_CANDIDATE | INPUT_STEP_OR_ASSEMBLY_ENVELOPE | NOT_FOR_MANUFACTURE
WP01-GSE-BASE-R2 | 1 | GROUND_SUPPORT_EQUIPMENT | NEW_PARAMETRIC_CANDIDATE | parts/WP01-GSE-BASE-R2.step | NOT_FOR_MANUFACTURE
WP01-GSE-FRAME-FOOT-R2 | 4 | GROUND_SUPPORT_EQUIPMENT | NEW_PARAMETRIC_CANDIDATE | parts/WP01-GSE-FRAME-FOOT-R2.step | NOT_FOR_MANUFACTURE
WP01-GSE-TOWER-R2 | 4 | GROUND_SUPPORT_EQUIPMENT | NEW_PARAMETRIC_CANDIDATE | parts/WP01-GSE-TOWER-R2.step | NOT_FOR_MANUFACTURE
WP01-GSE-TOWER-FOOT-R2 | 4 | GROUND_SUPPORT_EQUIPMENT | NEW_PARAMETRIC_CANDIDATE | parts/WP01-GSE-TOWER-FOOT-R2.step | NOT_FOR_MANUFACTURE
WP01-SA-FIXED-CROSSBEAM-R2 | 1 | GROUND_SUPPORT_EQUIPMENT | NEW_PARAMETRIC_CANDIDATE | parts/WP01-SA-FIXED-CROSSBEAM-R2.step | NOT_FOR_MANUFACTURE
WP01-HR-LOWER-OFFSET-A-R2 | 1 | GROUND_SUPPORT_EQUIPMENT | NEW_PARAMETRIC_CANDIDATE | parts/WP01-HR-LOWER-OFFSET-A-R2.step | NOT_FOR_MANUFACTURE
WP01-SA-ADJUSTABLE-SHOE-R2 | 1 | GROUND_SUPPORT_EQUIPMENT | NEW_PARAMETRIC_CANDIDATE | parts/WP01-SA-ADJUSTABLE-SHOE-R2.step | NOT_FOR_MANUFACTURE
WP01-SA-PAD-1-R2 | 1 | GROUND_SUPPORT_EQUIPMENT | ACCEPTED_STL_LOCAL_PLANE_CANDIDATE_NOT_MEASURED | parts/WP01-SA-PAD-1-R2.step | NOT_FOR_MANUFACTURE
WP01-SA-PAD-2-R2 | 1 | GROUND_SUPPORT_EQUIPMENT | ACCEPTED_STL_LOCAL_PLANE_CANDIDATE_NOT_MEASURED | parts/WP01-SA-PAD-2-R2.step | NOT_FOR_MANUFACTURE
WP01-HR-Z-GUIDE6-R2 | 4 | STANDARD_HARDWARE_GEOMETRY_CANDIDATE | NEW_PARAMETRIC_CANDIDATE | INPUT_STEP_OR_ASSEMBLY_ENVELOPE | NOT_FOR_MANUFACTURE
WP01-HR-Z-BUSH-R2 | 4 | STANDARD_HARDWARE_GEOMETRY_CANDIDATE | NEW_PARAMETRIC_CANDIDATE | INPUT_STEP_OR_ASSEMBLY_ENVELOPE | NOT_FOR_MANUFACTURE
WP01-HR-Z-JACK10-R2 | 2 | STANDARD_HARDWARE_GEOMETRY_CANDIDATE | NEW_PARAMETRIC_CANDIDATE | INPUT_STEP_OR_ASSEMBLY_ENVELOPE | NOT_FOR_MANUFACTURE
WP01-HR-Z-NUT-BLOCK-R2 | 2 | STANDARD_HARDWARE_GEOMETRY_CANDIDATE | NEW_PARAMETRIC_CANDIDATE | INPUT_STEP_OR_ASSEMBLY_ENVELOPE | NOT_FOR_MANUFACTURE
WP01-SA-Y-LOCATOR-BRACKET-R2 | 2 | GROUND_SUPPORT_EQUIPMENT | NEW_PARAMETRIC_CANDIDATE | parts/WP01-SA-Y-LOCATOR-BRACKET-R2.step | NOT_FOR_MANUFACTURE
WP01-MT-M4X12-ENVELOPE | 2 | STANDARD_HARDWARE_GEOMETRY_CANDIDATE | NEW_PARAMETRIC_CANDIDATE | INPUT_STEP_OR_ASSEMBLY_ENVELOPE | NOT_FOR_MANUFACTURE
WP01-HR-Y-RAIL-R2 | 2 | GROUND_SUPPORT_EQUIPMENT | NEW_PARAMETRIC_CANDIDATE | parts/WP01-HR-Y-RAIL-R2.step | NOT_FOR_MANUFACTURE
WP01-HR-TOWER-COLLAR-R2 | 2 | GROUND_SUPPORT_EQUIPMENT | NEW_PARAMETRIC_CANDIDATE | parts/WP01-HR-TOWER-COLLAR-R2.step | NOT_FOR_MANUFACTURE
WP01-HR-OVERHEAD-OFFSET-R2 | 2 | GROUND_SUPPORT_EQUIPMENT | NEW_PARAMETRIC_CANDIDATE | parts/WP01-HR-OVERHEAD-OFFSET-R2.step | NOT_FOR_MANUFACTURE
WP01-HR-OVERHEAD-LONGITUDINAL-R2 | 2 | GROUND_SUPPORT_EQUIPMENT | NEW_PARAMETRIC_CANDIDATE | parts/WP01-HR-OVERHEAD-LONGITUDINAL-R2.step | NOT_FOR_MANUFACTURE
WP01-HR-END-HANGER-A-R2 | 2 | GROUND_SUPPORT_EQUIPMENT | NEW_PARAMETRIC_CANDIDATE | parts/WP01-HR-END-HANGER-A-R2.step | NOT_FOR_MANUFACTURE
WP01-HR-Y-CARRIER-R2 | 2 | GROUND_SUPPORT_EQUIPMENT | NEW_PARAMETRIC_CANDIDATE | parts/WP01-HR-Y-CARRIER-R2.step | NOT_FOR_MANUFACTURE
WP01-HR-CANTILEVER-R2 | 2 | GROUND_SUPPORT_EQUIPMENT | NEW_PARAMETRIC_CANDIDATE | parts/WP01-HR-CANTILEVER-R2.step | NOT_FOR_MANUFACTURE
WP01-HR-CARRIER-NECK-R2 | 2 | GROUND_SUPPORT_EQUIPMENT | NEW_PARAMETRIC_CANDIDATE | parts/WP01-HR-CARRIER-NECK-R2.step | NOT_FOR_MANUFACTURE
WP01-HR-KEEPER-CROSSBAR-R2 | 2 | GROUND_SUPPORT_EQUIPMENT | NEW_PARAMETRIC_CANDIDATE | parts/WP01-HR-KEEPER-CROSSBAR-R2.step | NOT_FOR_MANUFACTURE
WP01-HR-KEEPER-NECK-R2 | 2 | GROUND_SUPPORT_EQUIPMENT | NEW_PARAMETRIC_CANDIDATE | parts/WP01-HR-KEEPER-NECK-R2.step | NOT_FOR_MANUFACTURE
WP01-HR-UPPER-PAD-R2 | 2 | GROUND_SUPPORT_EQUIPMENT | WHOLE_FOLDED_ARM_LOCAL_MAX_TANGENCY; CONTACT_LINK3_UNQUALIFIED | parts/WP01-HR-UPPER-PAD-R2.step | NOT_FOR_MANUFACTURE
WP01-HR-UPPER-GUIDE4-R2 | 4 | STANDARD_HARDWARE_GEOMETRY_CANDIDATE | NEW_PARAMETRIC_CANDIDATE | INPUT_STEP_OR_ASSEMBLY_ENVELOPE | NOT_FOR_MANUFACTURE
WP01-HR-UPPER-JACK10-R2 | 2 | STANDARD_HARDWARE_GEOMETRY_CANDIDATE | NEW_PARAMETRIC_CANDIDATE | INPUT_STEP_OR_ASSEMBLY_ENVELOPE | NOT_FOR_MANUFACTURE
WP01-HR-Y-ENDSTOP-R2 | 4 | GROUND_SUPPORT_EQUIPMENT | NEW_PARAMETRIC_CANDIDATE | parts/WP01-HR-Y-ENDSTOP-R2.step | NOT_FOR_MANUFACTURE
WP01-HR-LATCH-CLEVIS-R2 | 2 | GROUND_SUPPORT_EQUIPMENT | NEW_PARAMETRIC_CANDIDATE | parts/WP01-HR-LATCH-CLEVIS-R2.step | NOT_FOR_MANUFACTURE
WP01-HR-LATCH-HANGER-A-R2 | 1 | GROUND_SUPPORT_EQUIPMENT | NEW_PARAMETRIC_CANDIDATE | parts/WP01-HR-LATCH-HANGER-A-R2.step | NOT_FOR_MANUFACTURE
WP01-HR-LATCH-TOP-BRIDGE-R2 | 2 | GROUND_SUPPORT_EQUIPMENT | NEW_PARAMETRIC_CANDIDATE | parts/WP01-HR-LATCH-TOP-BRIDGE-R2.step | NOT_FOR_MANUFACTURE
WP01-HR-CAPTIVE-LOCK-PIN6-R2 | 2 | STANDARD_HARDWARE_GEOMETRY_CANDIDATE | NEW_PARAMETRIC_CANDIDATE | INPUT_STEP_OR_ASSEMBLY_ENVELOPE | NOT_FOR_MANUFACTURE
WP01-HR-PIN-CAPTIVE-HOUSING-R2 | 2 | GROUND_SUPPORT_EQUIPMENT | NEW_PARAMETRIC_CANDIDATE | parts/WP01-HR-PIN-CAPTIVE-HOUSING-R2.step | NOT_FOR_MANUFACTURE
WP01-HR-PIN-HOUSING-ENDCAP-R2 | 4 | GROUND_SUPPORT_EQUIPMENT | NEW_PARAMETRIC_CANDIDATE | parts/WP01-HR-PIN-HOUSING-ENDCAP-R2.step | NOT_FOR_MANUFACTURE
WP01-HR-PIN-HOUSING-SEAT-R2 | 2 | GROUND_SUPPORT_EQUIPMENT | NEW_PARAMETRIC_CANDIDATE | parts/WP01-HR-PIN-HOUSING-SEAT-R2.step | NOT_FOR_MANUFACTURE
WP01-HR-MANUAL-LEADSCREW8-R2 | 2 | STANDARD_HARDWARE_GEOMETRY_CANDIDATE | NEW_PARAMETRIC_CANDIDATE | INPUT_STEP_OR_ASSEMBLY_ENVELOPE | NOT_FOR_MANUFACTURE
WP01-HR-Y-DRIVE-NUT-R2 | 2 | STANDARD_HARDWARE_GEOMETRY_CANDIDATE | NEW_PARAMETRIC_CANDIDATE | INPUT_STEP_OR_ASSEMBLY_ENVELOPE | NOT_FOR_MANUFACTURE
WP01-HR-DRIVE-NUT-LINK-R2 | 2 | GROUND_SUPPORT_EQUIPMENT | NEW_PARAMETRIC_CANDIDATE | parts/WP01-HR-DRIVE-NUT-LINK-R2.step | NOT_FOR_MANUFACTURE
WP01-HR-SCREW-END-BEARING-R2 | 4 | STANDARD_HARDWARE_GEOMETRY_CANDIDATE | NEW_PARAMETRIC_CANDIDATE | INPUT_STEP_OR_ASSEMBLY_ENVELOPE | NOT_FOR_MANUFACTURE
WP01-HR-SCREW-END-MOUNT-67-R2 | 2 | GROUND_SUPPORT_EQUIPMENT | NEW_PARAMETRIC_CANDIDATE | parts/WP01-HR-SCREW-END-MOUNT-67-R2.step | NOT_FOR_MANUFACTURE
WP01-HR-SCREW-END-MOUNT-333-R2 | 2 | GROUND_SUPPORT_EQUIPMENT | NEW_PARAMETRIC_CANDIDATE | parts/WP01-HR-SCREW-END-MOUNT-333-R2.step | NOT_FOR_MANUFACTURE
WP01-HS-END-SWITCH-110-R2 | 2 | GROUND_SUPPORT_EQUIPMENT | NEW_PARAMETRIC_CANDIDATE | parts/WP01-HS-END-SWITCH-110-R2.step | NOT_FOR_MANUFACTURE
WP01-HS-END-SWITCH-290-R2 | 2 | GROUND_SUPPORT_EQUIPMENT | NEW_PARAMETRIC_CANDIDATE | parts/WP01-HS-END-SWITCH-290-R2.step | NOT_FOR_MANUFACTURE
WP01-HS-CARRIER-FLAG-R2 | 2 | GROUND_SUPPORT_EQUIPMENT | NEW_PARAMETRIC_CANDIDATE | parts/WP01-HS-CARRIER-FLAG-R2.step | NOT_FOR_MANUFACTURE
WP01-SB-FIXED-CROSSBEAM-R2 | 1 | GROUND_SUPPORT_EQUIPMENT | NEW_PARAMETRIC_CANDIDATE | parts/WP01-SB-FIXED-CROSSBEAM-R2.step | NOT_FOR_MANUFACTURE
WP01-HR-LOWER-OFFSET-B-R2 | 1 | GROUND_SUPPORT_EQUIPMENT | NEW_PARAMETRIC_CANDIDATE | parts/WP01-HR-LOWER-OFFSET-B-R2.step | NOT_FOR_MANUFACTURE
WP01-SB-ADJUSTABLE-SHOE-R2 | 1 | GROUND_SUPPORT_EQUIPMENT | NEW_PARAMETRIC_CANDIDATE | parts/WP01-SB-ADJUSTABLE-SHOE-R2.step | NOT_FOR_MANUFACTURE
WP01-SB-PAD-1-R2 | 1 | GROUND_SUPPORT_EQUIPMENT | ACCEPTED_STL_LOCAL_PLANE_CANDIDATE_NOT_MEASURED | parts/WP01-SB-PAD-1-R2.step | NOT_FOR_MANUFACTURE
WP01-SB-PAD-2-R2 | 1 | GROUND_SUPPORT_EQUIPMENT | ACCEPTED_STL_LOCAL_PLANE_CANDIDATE_NOT_MEASURED | parts/WP01-SB-PAD-2-R2.step | NOT_FOR_MANUFACTURE
WP01-HR-END-HANGER-B-R2 | 2 | GROUND_SUPPORT_EQUIPMENT | NEW_PARAMETRIC_CANDIDATE | parts/WP01-HR-END-HANGER-B-R2.step | NOT_FOR_MANUFACTURE
WP01-HR-LATCH-HANGER-B-R2 | 1 | GROUND_SUPPORT_EQUIPMENT | NEW_PARAMETRIC_CANDIDATE | parts/WP01-HR-LATCH-HANGER-B-R2.step | NOT_FOR_MANUFACTURE
WP01-HB-SPLIT-CLAMP-LOWER-R2 | 1 | GROUND_SUPPORT_EQUIPMENT | NEW_PARAMETRIC_CANDIDATE | parts/WP01-HB-SPLIT-CLAMP-LOWER-R2.step | NOT_FOR_MANUFACTURE
WP01-HB-SPLIT-CLAMP-UPPER-R2 | 1 | GROUND_SUPPORT_EQUIPMENT | NEW_PARAMETRIC_CANDIDATE | parts/WP01-HB-SPLIT-CLAMP-UPPER-R2.step | NOT_FOR_MANUFACTURE
WP01-HB-ROOT-OUTRIGGER-R2 | 1 | ONBOARD_HARDWARE_CANDIDATE | NEW_PARAMETRIC_CANDIDATE | parts/WP01-HB-ROOT-OUTRIGGER-R2.step | NOT_FOR_MANUFACTURE
WP01-HB-CLAMP-SPACER-R2 | 1 | ONBOARD_HARDWARE_CANDIDATE | NEW_PARAMETRIC_CANDIDATE | parts/WP01-HB-CLAMP-SPACER-R2.step | NOT_FOR_MANUFACTURE
WP01-HB-CONNECTOR-SLIDE-BRACKET-R2 | 1 | ONBOARD_HARDWARE_CANDIDATE | ADJUSTABLE_INTERFACE_BLANK; OEM_TAIL_NOT_BOUND | parts/WP01-HB-CONNECTOR-SLIDE-BRACKET-R2.step | NOT_FOR_MANUFACTURE
WP01-HB-CONNECTOR-MAST-R2 | 1 | ONBOARD_HARDWARE_CANDIDATE | NEW_PARAMETRIC_CANDIDATE | parts/WP01-HB-CONNECTOR-MAST-R2.step | NOT_FOR_MANUFACTURE

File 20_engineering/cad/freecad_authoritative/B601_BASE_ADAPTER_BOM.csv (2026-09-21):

item | qty | description | material | stock_or_source | mass_estimate_kg | note
1 | 1 | B601_BASE_ADAPTER machined part | AL6061-T6 | sawn plate 170x170x14 | 1.0395 | design estimate from 384988.78 mm^3; EXCLUDED from URDF authority
2 | 4 | M8 hex socket head cap screw (arm flange) | A2-70 / 8.8 | commercial | - | through Ø9 on BCD130; torque TBD
3 | 4 | M6 hex socket head cap screw (spacecraft side) | A2-70 / 8.8 | commercial | - | through Ø6.6 on 140x140; torque TBD
4 | 2 | dowel pin Ø6 x 12 | commercial | - | - | locating; reamed H7 TBD
5 | 1 | harness pass-through grommet (slot 40x12) | commercial | - | - | edge protection; part number TBD

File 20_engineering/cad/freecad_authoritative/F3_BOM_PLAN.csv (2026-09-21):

module | item | qty | class | material | process | mass_estimate_kg | confidence | freeze_status | note
S01_BASE_ADAPTER | B601_BASE_ADAPTER machined part | 1 | MAKE | AL6061-T6 | CNC 3-axis | 1.0395 | HIGH | F2_PASS | pilot complete; drawing human review pending
S01_BASE_ADAPTER | M8 SHCS arm-flange | 4 | BUY | A2-70 | commercial | - | MEDIUM | F3-P1 | BCD130; torque TBD
S01_BASE_ADAPTER | M6 SHCS spacecraft-side | 4 | BUY | A2-70 | commercial | - | MEDIUM | F3-P1 | 140x140 pattern
S01_BASE_ADAPTER | dowel pin Ø6x12 | 2 | BUY | commercial | commercial | - | MEDIUM | F3-P1 | locating H7 TBD
S02_STOWAGE | G07 main saddle body | 3 | MAKE | AL7075-T6 | CNC 3-axis | TBD | LOW | F3-P2_CANDIDATE | one per O13 station AFT/MID/FWD; CANDIDATE_HOLD
S02_STOWAGE | G07 contact pad | 3 | MAKE/BUY | PTFE/composite | machined | TBD | LOW | F3-P2_CANDIDATE | contact qualification HOLD
S02_STOWAGE | G07 guide cone | 3 | MAKE | AL6061-T6 | CNC | TBD | LOW | F3-P2_CANDIDATE | envelope only
S02_STOWAGE | G08 wrist grip saddle | 1 | MAKE | AL7075-T6 | CNC | TBD | LOW | F3-P2_CANDIDATE | six-DOF load path
S02_STOWAGE | G08 damping element | 1 | BUY | elastomer | commercial | TBD | LOW | F3-P2_CANDIDATE | damping TBD
S02_STOWAGE | ARM_STOW_SUPPORT_FRAME | 1 | MAKE | AL6061-T6 | CNC+weld | TBD | LOW | F3-P2_CANDIDATE | ties saddles to load spreading frame
S03_HDRM | HDRM latch body | 1 | MAKE | AL7075-T6 | CNC | TBD | LOW | F3-P2_CANDIDATE | engineering candidate NOT flight
S03_HDRM | release actuator envelope | 1 | ENVELOPE | - | - | TBD | LOW | F3-P2_CANDIDATE | envelope only; actuator model TBD
S03_HDRM | preload spring | 1 | BUY | spring steel | commercial | TBD | LOW | F3-P2_CANDIDATE | preload TBD
S03_HDRM | status sensor | 1 | ENVELOPE | - | - | TBD | LOW | F3-P2_CANDIDATE | envelope only
S03_HDRM | mechanical stop | 1 | MAKE | AL7075-T6 | CNC | TBD | LOW | F3-P2_CANDIDATE
S04_EE_V1 | wrist flange adapter | 1 | MAKE | AL7075-T6 | CNC | TBD | LOW | F3-P3 | mounts to J6 output
S04_EE_V1 | camera mount | 1 | MAKE | AL6061-T6 | CNC | TBD | LOW | F3-P3
S04_EE_V1 | F/T sensor mount | 1 | MAKE | AL6061-T6 | CNC | TBD | LOW | F3-P3 | sensor BUY
S04_EE_V1 | capture center datum | 1 | MAKE | AL6061-T6 | CNC | TBD | LOW | F3-P3 | kinematic datum only
S04_EE_V2 | compliant joint | 1 | MAKE | AL7075-T6+elastomer | CNC | TBD | LOW | F3-P3 | deferred to V2
S04_EE_V2 | passive damper | 1 | BUY | elastomer | commercial | TBD | LOW | F3-P3 | deferred to V2
S04_EE_V2 | guide cone | 1 | MAKE | AL6061-T6 | CNC | TBD | LOW | F3-P3 | deferred to V2
S05_HARNESS | per-joint connector | 6 | BUY | commercial | commercial | TBD | LOW | F3-P1 | routed per JOINT_ICD
S05_HARNESS | cable routing provisions | 6 | MAKE | AL6061-T6 (clips) | CNC/formed | TBD | LOW | F3-P1 | no tension/kink/through-axis
S05_HARNESS | strain relief | 6 | BUY | commercial | commercial | TBD | LOW | F3-P1
S07_LOAD_SPREADING | load spreading frame | 1 | MAKE | AL6061-T6 | CNC | TBD | LOW | F3-P2 | adapter->longerons path
S00_VENDOR_CORE | B601 arm core (6 joints+gripper) | 1 | BUY | - | - | 4.6956 (URDF) | HIGH | FROZEN_BUY | accepted URDF mass; vendor STEP envelope
S06_LINK_COVERS | link cover (optional) | 6 | MAKE | AL/composite | TBD | TBD | LOW | DEFERRED | only if thermal/MMOD rationale accepted (D8)

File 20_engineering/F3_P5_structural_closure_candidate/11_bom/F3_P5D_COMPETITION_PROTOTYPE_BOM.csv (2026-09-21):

item_id | item_name | type | qty | material | procurement | status
P01 | Adapter_Plate | machined_part | 1 | Al7075-T6 | in_house_CNC | MANUFACTURING_RELEASE
P02 | Central_Boss | machined_part | 1 | Al7075-T6 | in_house_CNC | MANUFACTURING_RELEASE
P03 | Spacecraft_Flange | machined_part | 1 | Al7075-T6 | in_house_CNC | MANUFACTURING_RELEASE
P04 | Load_Spreading_Frame | machined_part | 1 | Al7075-T6 | in_house_CNC | MANUFACTURING_RELEASE
P05 | Load_Bridge_Left | machined_part | 1 | Al7075-T6 | in_house_CNC | MANUFACTURING_RELEASE
P06 | Load_Bridge_Right | machined_part | 1 | Al7075-T6 | in_house_CNC | MANUFACTURING_RELEASE
P07 | Harness_Passage | machined_part | 1 | Al6061-T6 | in_house_CNC | MANUFACTURING_RELEASE
P08 | Maintenance_Access_Cover | machined_part | 1 | Al6061-T6 | in_house_CNC | MANUFACTURING_RELEASE
P09 | G07_Contact_Pad_Assembly | disc_spring_pair_plus_PTFE | 1 | GB1972_D50_25.4_t1.5 + PTFE_3mm | standard_part_plus_plate | COMPETITION_GRADE_PENDING_CALIBRATION
P10 | G08_Contact_Pad_Silicone | VMQ_Shore60A_2mm_30x30 | 1 | silicone_rubber | standard_sheet | COMPETITION_GRADE_PENDING_CALIBRATION
P11 | HDRM_Competition_Demonstrator | electromagnet_hold_plus_spring | 1 | electromechanical | procured | COMPETITION_DEMONSTRATOR
F01 | Screw_M5x16 | machine_screw | 16 | steel_A2-70 | standard | MANUFACTURING_RELEASE
F02 | Dowel_Pin_5h7x16 | locating_pin | 4 | steel | standard | MANUFACTURING_RELEASE
F03 | Loctite_Medium_Strength | threadlocker | 1 | adhesive | standard | MANUFACTURING_RELEASE
F04 | Cable_Harness_4core | harness | 1 | shielded | procured | MANUFACTURING_RELEASE
F05 | HDRM_Release_Driver | relay_driver_board | 1 | electronics | procured | COMPETITION_DEMONSTRATOR
F06 | HDRM_Position_Switch | micro_switch | 2 | electromechanical | standard | COMPETITION_DEMONSTRATOR

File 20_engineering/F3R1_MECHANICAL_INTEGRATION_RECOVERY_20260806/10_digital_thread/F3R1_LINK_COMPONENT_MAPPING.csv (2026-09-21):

urdf_link | cad_component | status
base_link | B51_REF_base_link_LINKLOCAL-1 | MAPPED
link1 | B51_REF_link1_LINKLOCAL-1 | MAPPED
link2 | B51_REF_link2_LINKLOCAL-1 | MAPPED
link3 | B51_REF_link3_LINKLOCAL-1 | MAPPED
link4 | B51_REF_link4_LINKLOCAL-1 | MAPPED
link5 | B51_REF_link5_LINKLOCAL-1 | MAPPED
link6 | B51_REF_link6_LINKLOCAL-1 | MAPPED
gripper_link | B51_REF_gripper_detail_LINKLOCAL-1 | MAPPED
gripper_left |  | MISSING
gripper_right |  | MISSING

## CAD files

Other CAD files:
01_project/competition/SERVICE_ROBOT_MECHANICAL_CONSOLIDATION_20260905/runs/wp07_system_20260907_0610/native/RET_S0_c03_v1/WP07_RETENTION_S0_LOCAL_CANDIDATE.SLDASM
01_project/competition/SERVICE_ROBOT_MECHANICAL_CONSOLIDATION_20260905/runs/wp07_system_20260907_0610/native/RET_S1_c03_v1/local_assembly_roundtrip.step
01_project/competition/SERVICE_ROBOT_MECHANICAL_CONSOLIDATION_20260905/runs/wp07_system_20260907_0610/native/work/WP07_WORK_PARKING.SLDASM
01_project/competition/SERVICE_ROBOT_MECHANICAL_CONSOLIDATION_20260905/runs/wp07_system_20260907_0610/native/WP07_ROBOT_RELEASED.SLDASM
01_project/competition/SERVICE_ROBOT_MECHANICAL_CONSOLIDATION_20260905/runs/wp08_retention_delta_20260907_1228/native/REAR_RIB_LOCAL/WP08_RIGHT_REAR_RIB.SLDASM
01_project/competition/SERVICE_ROBOT_MECHANICAL_CONSOLIDATION_20260905/runs/wp08_retention_delta_20260907_1228/native/work/WP08_WORK_PARKING.SLDASM
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

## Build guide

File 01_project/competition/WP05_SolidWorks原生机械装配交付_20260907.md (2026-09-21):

# 航天服务星与 B601：SolidWorks 原生零件及装配

本次接续中断工作，已把 WP04 的三态数字装配候选转换为 **443 个可复用 .SLDPRT 零件、3 个整机 .SLDASM、1 个连接局部 .SLDASM 和 1 个 B601 机械臂 .SLDASM**。零件含实际边界表示实体，整机引用这些零件，可在 SolidWorks 2024 中展开组件树、逐件选择、隐藏和继续设计。

[服务态整机](<F:/China Graduate Future Flight Vehicle Innovation Competition/20_engineering/WP05_SW_20260907/assemblies/WP05_ROBOT_SERVICE.SLDASM>) · [零件目录](<F:/China Graduate Future Flight Vehicle Innovation Competition/20_engineering/WP05_SW_20260907/parts>) · [原生交付核验](<F:/China Graduate Future Flight Vehicle Innovation Competition/20_engineering/WP05_SW_20260907/results/INDEPENDENT_NATIVE_DELIVERY_CHECK.json>) · [实例与零件清单](<F:/China Graduate Future Flight Vehicle Innovation Competition/20_engineering/WP05_SW_20260907/bom>)

SolidWorks 服务态整机

| 配置 | 原生装配文件 | 组件实例 | 解析实体数 |
|---|---|---:|---:|
| 服务态 | [WP05_ROBOT_SERVICE.SLDASM](<F:/China Graduate Future Flight Vehicle Innovation Competition/20_engineering/WP05_SW_20260907/assemblies/WP05_ROBOT_SERVICE.SLDASM>) | 585 | 966 |
| 开放停放态 | [WP05_ROBOT_PARKING.SLDASM](<F:/China Graduate Future Flight Vehicle Innovation Competition/20_engineering/WP05_SW_20260907/assemblies/WP05_ROBOT_PARKING.SLDASM>) | 585 | 966 |
| 释放态 | [WP05_ROBOT_RELEASED.SLDASM](<F:/China Graduate Future Flight Vehicle Innovation Competition/20_engineering/WP05_SW_20260907/assemblies/WP05_ROBOT_RELEASED.SLDASM>) | 585 | 966 |

[R07 连接局部装配](<F:/China Graduate Future Flight Vehicle Innovation Competition/20_engineering/WP05_SW_20260907/assemblies/WP05_R07_CONNECTIONS.SLDASM>)含 245 个实例，用于检查主结构、端塞、跨板、套管与相关连接关系；[B601 机械臂服务态装配](<F:/China Graduate Future Flight Vehicle Innovation Competition/20_engineering/WP05_SW_20260907/assemblies/WP05_B601_SERVICE.SLDASM>)含 10 个链接组件，保留整机 S 系下的服务姿态坐标。“开放停放态”不表示已满足发射收拢包络。

零件全部执行保存、关闭、重新打开，记录实体数、曲面体数、体积、包围盒和外部引用。整机保存后重新打开，逐项核对组件编号、实际依赖路径、安装变换、表示角色、固定状态和可解析实体。三态装配的组件、坐标、依赖和实体数量核对已通过。包含几何传递判据在内的独立回执核验状态为 **FAIL**，必需检查计数为 `{'PASS': 18329, 'FAIL': 48}`。此独立检查读取真实 COM 执行回执和文件 SHA；没有把回执检查称为另一 CAD 内核的独立装配试验。

**几何保留项：10 个零件未通过完整材料传递核验。** 当前文件可用于查看与继续修复，不得声明全套几何等价已通过。无效实体指标属于 OCC 对源或回导 BRep 的检查结果，不能直接认定为实物缺陷。逐零件/实体索引与数值见 [几何问题清单](<F:/China Graduate Future Flight Vehicle Innovation Competition/20_engineering/WP05_SW_20260907/results/GEOMETRY_HOLD_REGISTER.json>)。

| 零件 | 核验结果 | 源无效实体索引 | 回导无效实体索引 | 同核体积差 mm³ |
|---|---|---|---|---:|
| B601_base_link_LINKLOCAL | FAIL | [58, 59] | [59] | 未取得结果 |
| B601_link1_LINKLOCAL | FAIL | 未取得结果 | 未取得结果 | 0.002325166016817093 |
| B601_link2_LINKLOCAL | FAIL | [3, 4, 61, 62] | [1, 3] | 未取得结果 |
| B601_link3_LINKLOCAL | INCOMPLETE | 未取得结果 | 未取得结果 | 未取得结果 |
| B601_link4_LINKLOCAL | INCOMPLETE | 未取得结果 | 未取得结果 | 未取得结果 |
| B601_link5_LINKLOCAL | INCOMPLETE | 未取得结果 | 未取得结果 | 未取得结果 |
| B601_link6_LINKLOCAL | INCOMPLETE | 未取得结果 | 未取得结果 | 未取得结果 |
| B601_gripper_link_LINKLOCAL | FAIL | 未取得结果 | 未取得结果 | 0.006225599761819467 |
| B601_gripper_left_LINKLOCAL | INCOMPLETE | 未取得结果 | 未取得结果 | 未取得结果 |
| B601_gripper_right_LINKLOCAL | INCOMPLETE | 未取得结果 | 未取得结果 | 未取得结果 |

有 419 个零件通过实体数、曲面体数、体积及包围盒核对；这些指标不等同于逐面材料等价证明。另保留了 24 项跨内核标量体积差诊断，未放宽原数值阈值。对这 24 项执行了 SolidWorks 实际 STEP 回导，并逐件进行有时间上限的同一 OCC 内核材料差检查，结果为 `{'PASS': 14, 'FAIL': 4, 'INCOMPLETE': 6}`；FAIL 与 INCOMPLETE 均保留为未关闭项。详见 [回导几何验证](<F:/China Graduate Future Flight Vehicle Innovation Competition/20_engineering/WP05_SW_20260907/results/NATIVE_ROUNDTRIP_VALIDATION.json>)。STEP 导出前需激活目标文档并清空选择，依据 [SOLIDWORKS API 文档](https://help.solidworks.com/2024/english/api/sldworksapi/SolidWorks.Interop.sldworks~SolidWorks.Interop.sldworks.IModelDocExtension~SaveAs.html)。早期导出崩溃及失败诊断保留在 queue 与 results 中。

每态仍是 **193 项物理几何、355 项简化代理、37 项功能包络**；功能包络在原生主视图中隐藏，可通过组件树查看。585 个实例不等于 585 件完成选型的实物零件。10 个机械臂链接按原 STEP 内部实体与链接局部坐标保留；不同构型引用各自的安装变换。

现有 .SLDPRT 使用导入 BRep 特征，尚未重建全套草图、尺寸和加工特征树；.SLDASM 使用固定姿态组件，尚未建立可驱动的完整配合机构。不能从本次原生转换推导全机无干涉、连续动作通过、强度通过或制造放行。SW 默认材质或密度不用于整机质量结论。质量未知字段保留为空；历史零件号按来源保留，仍需结合实际候选几何校核，特别是旧 M4×22 标识与已缩短的前端螺钉。

为控制内存，建议一次打开一个整机装配；整机按轻化形式保存，编辑时再解析所需组件。打开时保留本目录的 `assemblies/` 与 `parts/` 相对目录关系；当前实际重开检查的依赖均在本交付目录内。此轮未进行搬移目录后的独立重开试验。`bom/WP05_INSTANCES_*.csv` 每态逐实例列出原编号、角色、原零件号、规范零件路径及来源；`WP05_CANONICAL_PARTS.csv` 分态列数量并取三态最大值，不把互斥配置用量相加作采购数量。

质量表分别保存 CAD 来源字段与已绑定的数字身体分配字段。原来源字段有 188 项非空；数字身体账本有 198 项分配与 387 项 UNKNOWN，其中 10 个机械臂链接质量从已接受 URDF 逐链接核对、仅计一次。数字分配合计 20.733608541407722 kg，不是完整整机实测质量，也不能与原来源列再次相加。

现在可以进入 SolidWorks 接口细化与装配设计审查：先逐项处理几何保留项、重建关键连接件参数特征，再建立保持器导向、防脱、止挡及退出锁止的完整结构和运动配合，再检查盖板、设备、工具与线束装入路径。随后用实际 B601/器件 ICD、材料、紧固件和载荷输入完成尺寸链、连接承载、预紧及完整制造图。既有重点未关闭项包括 2.5 mm 沉孔残底、1.13276253 mm 叉座净距、0 mm 旧侧螺钉名义间隙、八处螺纹代理未知、整机连续避碰以及质量未知项，仍以 [WP04 详细设计输入清单](<F:/China Graduate Future Flight Vehicle Innovation Competition/01_project/competition/SERVICE_ROBOT_MECHANICAL_CONSOLIDATION_20260905/runs/wp04_robot_assembly_20260906_175153/MECHANICAL_INPUT_REGISTER_ZH.md>) 和 [装配工序](<F:/China Graduate Future Flight Vehicle Innovation Competition/01_project/competition/SERVICE_ROBOT_MECHANICAL_CONSOLIDATION_20260905/runs/wp04_robot_assembly_20260906_175153/ASSEMBLY_PROCEDURE_ZH.md>) 为入口。

已另附 [SolidWorks 后续细化与检查工序](<F:/China Graduate Future Flight Vehicle Innovation Competition/01_project/competition/WP05_SolidWorks后续细化与检查工序_20260907.md>)，明确几何修复、参数特征、可动配合、保持机构、装入路径与图纸的后续执行顺序。这些步骤仍待实施。

本轮 33 项输入文件和前轮封存的 596 个文件 SHA 均保持一致，见 [来源保护](<F:/China Graduate Future Flight Vehicle Innovation Competition/20_engineering/WP05_SW_20260907/results/SOURCE_PRESERVATION_FINAL.json>)。原研究 Gate、制造状态和硬件许可没有升级。

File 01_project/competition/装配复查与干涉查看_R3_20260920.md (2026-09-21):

# R3装配复查与干涉位置查看

本轮针对“装配再次检查”和“展示可能干涉的地方”执行。当前R3固定服务态原生装配可读取与重建；新增接口预留区域在三个固定姿态下没有外部实体穿透。全星逐对干涉、连续运动扫掠、公差/热变形/振动间隙和实体安装件验收仍未完成。

## 查看入口

- [可旋转三维查看器](../../20_engineering/SERVICE_STAR_B601_INTERFACE_R3_20260920/views/ASSEMBLY_INTERFERENCE_VIEWER.html)：拖动旋转、滚轮缩放、点击图例隐藏零件；窄窗口中按A/B/C向下排列。自含页面可直接在本机浏览器打开，不需要外网。
- [三处位置对照图](../../20_engineering/SERVICE_STAR_B601_INTERFACE_R3_20260920/views/ASSEMBLY_INTERFERENCE_LOCATIONS.png)
- [SolidWorks整星实截图](../../20_engineering/SERVICE_STAR_B601_INTERFACE_R3_20260920/views/SERVICE_STAR_SERVICE_R3_RESOLVED.png)
- [当前原生装配](../../20_engineering/SERVICE_STAR_B601_INTERFACE_R3_20260920/native/SERVICE_STAR_SERVICE_R3.SLDASM)：依赖同工作区R1/R2原生目录，不是独立Pack-and-Go。

## 应重点查看的位置

| 标记 | 零件/路线 | 本次几何复算 | 实际含义与后续修正对象 |
|---|---|---|---|
| A | R3局部功能线路与`trunk_clip_standoff_-140` | 间距0.50 mm，交叠0；最近点S坐标(-101,-15.5,5)与(-101,-15,5) mm | 当前无穿透，但间隙较小。需结合实际线径、接头出线方向与弯曲半径调整局部走廊/支架，随后复核制造与动态裕量。尚未给真实电缆放行。 |
| B | R2 `release_power_data_route_0_0`与`WP01-MT-M3RB-REUSED` | 间距0.75 mm，交叠0；最近点约(20,-85.75,120)与(20,-85,120) mm | R2已完成几何绕行；名义小间距仍需变形与公差预算。两条逻辑路线共享走廊，不代表两根实际电缆已经物理分开。 |
| C | CF1历史模块与`CLAMP_DUAL_BASE` | 精确交叠384.100711 mm³，红色为布尔交集 | CF1旧候选未装入当前R3。该热/电模块布局仍需重设计；旧有限平移搜索未给出可用解，不能靠展示图宣称恢复安装。 |
| 接口相接 | R3局部线路与`connector_arm_drive` | 距离0，实体交叠0 | 线路包络到达旧入口平面，不代表OEM接头针脚/锁紧/插拔空间已经定义。 |

图中绿色/蓝色表示相关几何，黄色表示功能线路，红色表示真实布尔交叠，洋红线表示最近点。颜色没有赋予材料或制造属性。A/B是当前装配局部；C是明确分列的旧候选。

## 本轮修正与错误记录处置

1. 修正新复查脚本的坐标配对：历史`v6parts`整星坐标STEP不能再乘规范化零件到整星的变换。误配曾产生P60主机安装柱27.725992 mm³、拉杆16.000342 mm³的假穿透。改用`NEUTRAL_SOURCE_MAP.json`中与原生零件一致的canonical STEP后，两者真实名义距离为23.730849/26.230849 mm，交叠均为0。此项修正了检查程序，未据误报移动任何装配零件。
2. 修正SolidWorks实体复查方式：仅用轻量化加载无法完整统计实体，现采用只读打开并显式解析全部零件，再核对实体数与重建。中断、未完全解析的检查收据保留，不作为通过依据。
3. 原生装配727个锁定文件在检查前后哈希一致；没有保存重建后的只读文档，也没有修改R1/R2封存件。

## 有效复查证据

- `NATIVE_ASSEMBLY_RECHECK_V4.json`：14个直接装配组、1110个实例、677个唯一零件文件、1520个实际实体；全部解析且固定，引用与总变换吻合；最大变换元素差6.66e-16；冷打开错误/警告0，重建成功、待重建项0。
- `GEOMETRY_ASSEMBLY_RECHECK_V2.json`：最终服务态原生引用/变换逐项绑定；三个固定姿态共3327个周边实例筛查，36对精确实体交叠检查，R3区域无外部穿透。不是全星任意两零件的穷举无干涉结论。
- `INTERFERENCE_VISUALIZATION.json`：A/B名义间距与C交叠体积由锁定STEP重新计算，记录每个几何源哈希及最近点。
- 旧`GEOMETRY_ASSEMBLY_RECHECK.json`仅作为**坐标配对错误诊断**保留，由V2显式给出失效原因；不是当前真实装配碰撞清单。

应继续推进的是A/B实际线束几何和裕量、CF1模块重新布置与导热压紧、控制板真实安装支撑和接头定义。当前仍不能宣称全星机电/热控设计已完整收口或可直接上电。

SolidWorks加载选项与状态解释依据：[官方OpenDoc选项](https://help.solidworks.com/2021/english/api/swconst/SOLIDWORKS.Interop.swconst~SOLIDWORKS.Interop.swconst.swOpenDocOptions_e.html)、[官方零件解析状态](https://help.solidworks.com/2023/english/api/swconst/SolidWorks.Interop.swconst~SolidWorks.Interop.swconst.swComponentSuppressionState_e.html?id=2a9fc1c0a74a42ccac96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)。

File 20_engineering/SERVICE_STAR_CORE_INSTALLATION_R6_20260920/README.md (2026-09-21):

# R6 倾斜安装探索记录（已撤下）

用户要求优先水平安装，本目录倾斜布局不作为最终交付。后续转入同级 SERVICE_STAR_CORE_INSTALLATION_R6H_20260920。

保留几何搜索、干涉修正、初步模型覆盖与原生导入诊断；MAIN 局部35位号外形来源仍可复用。不存在已放行的倾斜原生总装。

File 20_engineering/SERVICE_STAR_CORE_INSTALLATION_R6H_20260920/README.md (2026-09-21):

# R6H 核心电气水平数字安装

本轮已完成水平MAIN、局部P60支承调整、接口板热桥及推进准备的数字候选。整星设计、制造、上电和飞行资格未完成。

主入口：[交付报告](<F:/China Graduate Future Flight Vehicle Innovation Competition/01_project/competition/核心电气水平安装与推进装配准备_R6H_20260921.md>)。原生文件为 `native/SERVICE_STAR_SERVICE_R6H.SLDASM`；查看图为 `views/R6H_HORIZONTAL_INSTALLATION_VIEWER.html`。

机器状态：`results/FINAL_DELIVERY_STATUS.json`；独立审查：`results/reviewer/FIVE_DIMENSION_REVIEW.md`。最终15组/1153叶/1602实体以分层只读冷打开复验为准，不依赖已失败的整机同时解析尝试。

包内清单 `PACKAGE_SHA256.csv` 的路径相对于项目根；`SOURCE_DEPENDENCIES_SHA256.csv` 包含原生引用及其哈希。R1/R4等外部引用未复制，必须保留本工作区目录结构。本包没有Pack and Go、完整材料质量或运动配合放行信用。

历史失败回执、被拒候选和已撤下R6仅保留来源证据。后续AUX/STOP见R7，尚未计入本版总装。

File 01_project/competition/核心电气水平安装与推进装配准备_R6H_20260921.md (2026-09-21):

# 核心电气水平安装与推进装配准备 R6H

日期：2026-09-21。结论：本轮水平数字安装、原生总装复验和推进接口准备已完成；保留独立审查列出的工程待验项。当前等级为地面工程样机数字候选，整星完整设计、制造、上电和飞行资格均未完成。

## 交付入口

- [SolidWorks 服务姿态总装](<F:/China Graduate Future Flight Vehicle Innovation Competition/20_engineering/SERVICE_STAR_CORE_INSTALLATION_R6H_20260920/native/SERVICE_STAR_SERVICE_R6H.SLDASM>)
- [交互装配查看器（离线 HTML）](<F:/China Graduate Future Flight Vehicle Innovation Competition/20_engineering/SERVICE_STAR_CORE_INSTALLATION_R6H_20260920/views/R6H_HORIZONTAL_INSTALLATION_VIEWER.html>)；本机会话地址为 http://127.0.0.1:8768/R6H_HORIZONTAL_INSTALLATION_VIEWER.html。
- [水平安装说明、尺寸和顺序](<F:/China Graduate Future Flight Vehicle Innovation Competition/20_engineering/SERVICE_STAR_CORE_INSTALLATION_R6H_20260920/docs/hardware/HORIZONTAL_INSTALLATION.md>)
- [推进设计装配移交](<F:/China Graduate Future Flight Vehicle Innovation Competition/20_engineering/SERVICE_STAR_CORE_INSTALLATION_R6H_20260920/docs/PROPULSION_ASSEMBLY_HANDOFF.md>)
- [独立五维审查及剩余项](<F:/China Graduate Future Flight Vehicle Innovation Competition/20_engineering/SERVICE_STAR_CORE_INSTALLATION_R6H_20260920/results/reviewer/FIVE_DIMENSION_REVIEW.md>)

原生总装依赖本工作区 R1/R4 等目录中的文件；保持目录结构后用 SolidWorks 2024 打开。尚未制作可脱离本工作区的 Pack and Go 包。零件含导入实体，装配以固定位置表示；不声明原生特征树或配合驱动运动已经完成。

## 本轮已完成

MAIN 主输入板保持水平，板原点 S=[-164,86,11.5] mm，旋转矩阵为 I。采用四点支撑，P60 仅调整一个支点并局部修改支承件；接口板增加传热块和绝缘垫。整星外形未扩展。

| 项目 | 已验证结果 |
|---|---|
| 装配改动 | 新增23个实例、4个几何改件、5个仅改变位姿的既有实例 |
| 原生文件 | 27个新SLDPRT、4个新建/重建子装配、1个服务姿态总装 |
| 装配核对 | 15个直接子装配、1153个叶实例、1602个实体实例；路径、固定状态与变换核对通过 |
| 干涉复核 | 三种固定姿态增量检查及独立逐实体增强复验通过；受检范围无体积穿透或未决布尔 |
| 承压接触 | 34处名义接触确认；不提供强度或预紧合格信用 |
| 材料 | 新增热桥6061 Alloy赋值并冷读回；混合PCBA、垫片及整星材料质量未闭合 |
| 推进准备 | 绑定9个保留对象与1个局部改托盘，整理9项OEM缺口及12项工作单 |

SolidWorks 复验采用顶层冷打开与15个子装配分别冷打开、完全解析的分层方法，组合核对全局变换；不宣称已在一个会话中同时完全解析整个装配。此次只读复验未保存CAD；既有失败与内存中止回执原样保留。所有受锁原生文件哈希一致。

MAIN 有35个位号的分级外形表示，四个元件仍使用6 mm假定高度。1.60 mm板体是总层机械包络，不是Cu/FR4逐层材料模型；原生往返40实体双向形状差为空，但不据此宣称PCBA内部零干涉或质量真值。详见安装说明与独立报告。

## 保留待验项与下一断点

1. **安装和承载**：最近隔柱与旧适配器名义间隙0.50 mm；隔柱2旁保留旧孔，孔间余肉1.072 mm。需公差、孔边承压/净截面/疲劳、预紧、工具及装入路径验证。P60托盘耳台需要带耳台加工件或经验证的连接工艺。
2. **继续AUX/STOP**：既有R7已建立板件与水平位置搜索，AUX当前候选原点为S≈[30.5,31.5,80] mm、平面内转90°，安装支架尚未建成。STOP尚无已接受的水平安装位置。搜索没有证明所有可用位置都不存在，不得直接删掉预留区或宣称必须扩大整星。下一步从R7输入和负结果接续最小改动的支架、走廊与位置复核。
3. **线缆与电热**：安装端口表仅为参考点，尚未完成实际插合点、逐针、电缆下料、应力释放、STOP/AUX实装与Q201热路径。热桥绝缘垫的MPN、导热率、压缩厚度、耐压、接触压力和保持方式待补。
4. **推进装配**：先补OEM同版本CAD/安装孔系和供电/命令接口，再建立喷口位置、方向、最小脉冲、并发限制、质心变化与欠驱动可达性账本；喷口、储箱、管路和羽流没有以假值冻结。

[R7 AUX候选位姿与未完成标记](<F:/China Graduate Future Flight Vehicle Innovation Competition/20_engineering/SERVICE_STAR_AUX_STOP_INSTALLATION_R7_20260921/inputs/AUX_INSTALL_POSE.json>)；[R7 搜索结果和STOP未找到记录](<F:/China Graduate Future Flight Vehicle Innovation Competition/20_engineering/SERVICE_STAR_AUX_STOP_INSTALLATION_R7_20260921/results/BOARD_POSE_SEARCH.json>)。R7是未完成的后续探索，不包含在本轮已安装计数中。

此前电气选型继续由 SERVICE_STAR_ELECTRICAL_LATEST.json 指向R5E；本轮只新增核心安装指针。R17历史移交、旧R1–R5E文件及科学Gate保持原有含义。撤下的倾斜R6不再作为现行装配入口。

R6H 实际CAD装配图

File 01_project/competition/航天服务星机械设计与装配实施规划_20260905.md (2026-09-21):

# 航天服务星与 B601 机械臂：机械设计、装配和具身任务实施规划

日期：2026-09-05。规划依据：用户要求以完成产品为目标重新规划，不以历史 Gate、比赛期限或旧流程限制作为新计划的前置条件。本文件是本轮新规划，不修改历史资产或结果。

**下一阶段的目标：形成同一配置的参数化整星总装、可加工装配的工程文件、完成联调的实体工程样机，以及与实装配置一致的机器人数字模型。**

## 1. 总体取舍与完成定义

建议首版沿用 B601 六轴执行机构，允许重新设计母线结构、臂根安装、支承/保持释放机构、末端接口、翼根及线束布置。将 12U 级作为总体尺度目标；严格标准部署器适配与任务优先的 12U 衍生构型应在第一个工作包中明确选择。以下路线推荐任务优先的完整服务星工程样机作为首轮实现目标，不将任何未经计算的放大尺寸预先定为最终值。

一个关键规则是：**总体包络由完整机器人、保持释放机构、太阳翼及内部设备共同确定。** 先比较少量完整布局方案，以工作能力、可装配性、收拢/展开可靠性、质量和制造复杂度选择一个，随后进入详细设计。若必须适配指定部署器，则用它的具体接口要求作为方案筛选输入；不能把外包络问题一直留到出图以后。

“完成”分成三个可直接检查的产品状态：

| 产品状态 | 必须交付 |
|---|---|
| 数字机械样机完成 | 唯一主原生总装；真实关键实体与接口；收拢/释放/展开/工作状态；运动与线束检查；逐件质量；可编辑参数；装配图、BOM 与制造图 |
| 实体工程样机完成 | 加工采购件可装；保持/释放/展开能运行；驱动与传感器接通；尺寸、质量、摩擦/间隙等实测；整机任务演示与故障停机验证 |
| 飞行产品完成 | 在前两项基础上，完成特定任务的发射接口、材料与机构环境适应性、环境试验和可靠性工作；试验等级来自实际任务 |

首轮按前两项组织实施，并在设计时保留飞行产品所需的接口、材料、热与环境设计考虑。CAD 检查和实体测试各自回答不同问题：是否符合设计要求，以及是否能在预期使用条件下完成任务。[NASA 产品实现](https://www.nasa.gov/reference/5-0-product-realization/)

## 2. 首个工作包：总体骨架与机器人安装联合设计

这是立即应开始的设计工作。输出必须是一套可查看、可调整、可比较的整机装配模型。

**先写一页设计输入表。** 至少明确任务对象及抓持界面、目标惯量/相对运动范围、末端工具、臂工作区域、母线包络方案、供电与驱动设备、相机/F/T 安装、制造手段及首版实体试验形式。区分已测、厂商数据和用于设计扫掠的假设值。未知输入采用明示区间，不靠补一个数宣称完成。

然后建立参数化骨架，统一 S 星体系、臂根、各关节、末端 TCP、相机、力传感器、翼根和分离界面坐标。主参数至少包括母线长宽高、框梁位置、臂根平移/转角、完整关节姿态、支承站位、翼根站位、设备安装面及维护通道。

用同一完整臂、末端、保持装置及设备集合，比较 2–3 个布局，例如前端根部/沿侧收拢、侧置根部/沿纵向收拢、为工作区调整母线截面的方案。方案比较至少包含完整收拢尺寸、连续设备舱、承力拓扑、初始释放路径、太阳翼避让、活动线束空间和加工装配难度。选定一个主方案后停止扩展并行构型，详细零件围绕该方案推进。

首包交付六件内容：

1. 设计输入表与布局选择记录。
2. 一套可驱动的总体骨架和完整低细节总装。
3. 收拢、解除保持、初始展开、完全展开、工作姿态五种状态。
4. 臂根与收拢保持点的载荷路径图。
5. 线束活动区、翼扫掠区、设备/工具/维护保留空间。
6. 后续需设计的零件清单、接口尺寸表和初步质量预算。

这里允许设备用明确的采购包络表示；决定碰撞、安装或承载的几何应有足够细节，不用坐标轴代替连杆，也不以总包络块代替实际可用内舱。

## 3. 设计和装配的主工作包

| 顺序 | 工作包与责任 | 具体工作 | 完成条件 |
|---|---|---|---|
| WP01 | 总体/主CAD | 完整布局、坐标、安装、状态、参数骨架 | 所有主要部件有位置；选定一套布局；安装变换固定；收拢及初始释放有可检查模型 |
| WP02 | 主结构/臂安装 | 框梁、端框、承载桥、M3R、定位与紧固、工具通道 | 从臂根到主结构的真实连接可追踪；安装孔/定位/紧固可装；初步载荷下刚度与强度有依据 |
| WP03 | 收拢与释放机构 | 承载支承、接触垫、保持装置、驱动/弹簧、释放确认、地面复位 | 保持载荷分流明确；机构脱开后不阻挡首段运动；释放反馈和复位操作可实现 |
| WP04 | 臂/末端/线束/感知 | 夹爪与工具接口、传感器/相机、连接器、线束固定与活动段、驱动安装 | 末端可安装标定；全范围线束无过拉/夹挤/扭转累积超限；驱动与传感器具有布线和散热空间 |
| WP05 | 翼与内部设备 | 翼根/铰链/锁扣、展开线束、设备板、轮组/电源/计算机/推进等安装 | 展开顺序明确；臂翼互不侵入；设备能装能拆；必要散热与视场/喷流避让成立 |
| WP06 | 整机验证与设计收敛 | 完整运动检查、关键载荷/结构/柔性分析、公差、质量/CG/I、故障工况 | 每个要求有结果；不满足项落实到具体零件修改，修改后重查受影响部分 |
| WP07 | 制造与分总成装配 | 材料工艺、二维图、公差、标准件、采购BOM、检验、工装、分总成首装 | 加工图可供制造；关键分总成试装可运行；实测差异已回写设计 |
| WP08 | 整星装配与具身任务联调 | 按装配顺序整合、标定、模型更新、观测到动作闭环 | 同一实装配置完成代表任务；模型、驱动、标定和机械版本一致 |

WP02、WP03、WP04 必须密切联合。WP05 在 WP01 接口明确后可并行；WP06 从 WP01 起穿插进行，在详细设计收敛后完成整机复核。不能把强度、线束或装配工具可达性全部推迟到 WP06。NASA 的产品集成方法将装配策略、接口检查和子系统相互作用一起规划，这也是此工作包安排的依据。[NASA 产品集成](https://www.nasa.gov/reference/5-2-product-integration/)

## 4. 三项必须先解决的设计耦合

**承载、支撑和释放。** 收拢状态的载荷由保持点/支承/HDRM 传入所连接主结构，并到分离界面；展开状态的操作反力通过臂根、转接与承载桥进入母线。应明确两种状态的分流关系、刚度、公差和接触预紧，不能假设都经同一串联路径，也不能默认关节减速器独自承担保持载荷。是否需要一个或多个主动释放点由载荷、运动和故障分析决定。

**运动、线束和其他展开件。** 线束的真实外径、最小弯曲半径、扭转能力、余长、固定点、插拔方向和应力释放应与每个关节一起设计。首个解除保持动作、臂与太阳翼谁先展开、失电后的机构状态，都需要通过完整序列选择；不能由零件看起来分离就认定路径安全。

**布局、质量和动态性能。** 每个实际安装组件独立计质量，设备替换预算块时避免重复。目标质量本身不是在轨关节重力负载；接触反力和关节需求应由目标惯量、相对运动、接触过程、臂动作及停机策略推导。结构刚度、姿态资源、功率、传感器视场及计算设备布局共同影响任务能力。

航天机构材料、润滑、表面处理与环境适应性需要在设计中考虑，不能等结构定型后再整体替换。[NASA 小航天器结构、材料与机构](https://www.nasa.gov/smallsat-institute/sst-soa/structures-materials-and-mechanisms/)

## 5. 参数化与模型交付规则

选择一个能够稳定编辑、重建、装配和出图的原生 CAD 作为主设计源。允许其他内核用于检查或转换，但各软件不分别维护一套不同的机械结构。

每个关键零件具有零件号、修订、材料/工艺、主要参数、接口、所属总装和质量来源。紧固与定位特征要能追溯到装配接口。至少检验几组设计参数扰动后，模型能够重建、接口随动且没有意外自由度或悬空引用。正常装配接触和机构配合需明确定义，不能一律当干涉，也不能将所有小穿透当正常。

由这套主装配派生可视几何、碰撞几何、机器人拓扑、质量惯量和坐标参数。不同用途可以有不同精度，但都要能对应到同一物理部件与姿态；简化模型要保留所需包络与接触特征，并说明误差。

## 6. 实体装配与最小验证任务

建议先做机械臂/末端、保持释放、太阳翼、内部设备四类分总成，再进行整星首装。总体顺序初案为：主结构与臂根接口 → 内部设备和主线束 → 机械臂及末端传感器 → 保持机构与翼根/翼 → 外覆盖件。具体顺序由安装路径和工具空间调整；每次封闭前检查线束、紧固与连接器，并保留拆卸返修路径。

试制优先件是臂根/支承/HDRM 接口样件和线束活动段样件。这些试装可在详细设计后期提前完成，用实际摩擦、间隙、插拔和弯曲行为修正 CAD，再加工整星主结构。不要仅凭外观样机决定承载结构。

最小工况集合必须覆盖：保持、解除保持、初始展开、完全展开、典型抓持、工作区边界、臂翼最近位置、线束最不利姿态、携载运动、释放，以及断电/失联/受阻后的停止和保持。接触允许区、最小净间隙、速度/力/位姿要求和误差裕量在具体试验前写清。

记录实测尺寸、质量、关节零位、间隙/回差、摩擦、夹爪力、机构释放/展开行为、线束反力和驱动限制。地面试验需要与其负载匹配的支撑/卸载工装；它提供部件与系统工程证据，自由漂浮动力学另由相符条件的模型或试验验证。

## 7. 具身智能接口从首轮机械设计开始

TCP、相机、F/T、编码器、限位和释放确认传感器的安装、刚度、视场、线缆与标定操作空间纳入 WP01–WP04。驱动器与计算机的供电、热路径、通信和时间同步同时进入设计。这里要确定的是接口、性能需求与可实现的安装位置，后续算法可以并行迭代。

首个端到端任务按由易到难的序列完成：识别静止目标 → 规划可达接近姿态 → 检查几何与物理约束 → 低速接近和抓持 → 接触反馈/保持 → 释放；随后再扩展运动目标与抓后稳定。第一轮固定基座或卸载条件下的演示，不能被称为已经证明自由漂浮捕获性能。

最终交付的机械版本、BOM、机器人模型、驱动配置与标定文件相互对应。智能策略能够获得当前可达域、碰撞几何、关节限制、末端状态和接触反馈；不能只收到一个视觉漂亮但没有物理接口的网格。

## 8. 首轮实施节奏与人员并行

第一个短周期只完成 WP01 及 WP02–WP04 的联合初案。若使用一周冲刺，其日程可作为工作分解目标，而非保证完成的工期：第 1 天整理设计输入/骨架；第 2–3 天比较完整布局；第 4 天确定根部、支承/释放与线束方案；第 5 天输出主方案总装、关键路径和需试制接口。

之后按三个连续增量推进：关键机械子系统详细设计 → 完整数字样机与图纸 → 分总成和整星首装联调。加工采购周期单独排入，按实选供应件和工艺报价确定，不与 CAD 完成日混同。

可并行的四项责任为：总体与主CAD、承载/机构与制造、线束/航电/感知接口、分析与数字模型。各负责人共享同一接口表和主装配，不独立改变对方安装面。每次集成会议只处理具体装配问题、设计修改与验证结果，确保投入持续转化为可用部件和完整装配。

**下一项具体行动：启动 WP01“完整服务星总体骨架与 B601 安装联合设计包”，在一套主装配中首先打通臂根—保持支承—释放路径—活动线束—设备空间这组耦合。**

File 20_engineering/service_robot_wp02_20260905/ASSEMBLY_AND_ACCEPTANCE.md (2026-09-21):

# WP02 首件装配与验收单

日期：2026-09-05。对象：根部承载桥/锚固候选＋两站可调支承＋地面保持Y滑台＋真实线束接口。状态：`DESIGN_AND_OFFLINE_VERIFICATION`。本轮执行CAD零件化与离线检查；下述台架操作是可执行的后续试装程序，没有在真实机械臂上执行。

高支承、保持Y滑台与其锁止/传感器支架为 `GROUND_SUPPORT_EQUIPMENT`。根桥/根板/纵梁锚固为 `ONBOARD_HARDWARE_CANDIDATE`。夹具与独立托持设备载荷计入地面账，不能计入飞行BOM，也不能把其支撑效果用于宣称在轨保持构型成立。

当前GSE正Y侧使用公共立柱S.x=40 mm、S.y=155/315 mm、柱顶z=690 mm，公共吊梁z=660 mm；负Y侧两站立柱y=-155 mm。实际翼动作需由独立托持接管载荷后移开GSE，并对移除后的台架、线缆及翼展开路径重新检查。当前GSE布局不构成翼动作已兼容的证据。

## 首件装配顺序

每一步记录零件修订、实装照片、尺寸/仪器、操作者、异常与整改。紧固件规格、啮合长度、力矩、润滑/防松和重复使用策略当前依图纸/载荷输入逐项确定，不给经验力矩。所有“检查”栏在实际执行前均为 `NOT_EXECUTED_PHYSICAL`。

| 步骤 | 可操作的装配动作 | 当步检查/记录 | 继续条件和返修路径 |
|---|---|---|---|
| A01 | 核对厂家接口/线缆图号与臂序列号，测根部基准与四孔 | 每孔中心/孔型/径/有效深度；承载面/定位；见测量登记M01–M10 | 图/物冲突保持独立记录，不修孔“凑合”；可先用无载模板核对 |
| A02 | 将代表性框梁/端框段固定到独立台架 | 台架能力、夹紧与抗倾覆、S系方向、接口基准 | 台架/托持不依赖未验证的新支承或机械臂制动 |
| A03 | 空载装根部承载桥、角撑和纵梁锚固件 | 定位/紧固路径连续；螺栓头和螺母的插入/扳手方向；孔边和啮合 | 紧固顺序先定位后按计划分次紧固；不可达处先改件再封闭 |
| A04 | 装M3R B，再装A及定位/级间紧固件 | A/B环槽真实嵌套；四M6、八M5及定位件的实际对偶；厂家小件依据见[VENDOR_GEOMETRY_PROBE](results/VENDOR_GEOMETRY_PROBE.json) | 内核孔/平面不是实物计量；不把孔径当已确认螺纹；确认销拔出和螺母更换路径 |
| A05 | 用额定独立托持/卸载设备托住臂，保持接触面无预载，装根部 | 根frame[90,0,125.15]mm与承载面z127.555分别量测；工具进入/退出、臂缆不受重量 | 未确认根部承载前不撤托持；不得假定断电关节自锁 |
| A06 | 空载装A/B地面支承底座、调节件及下垫 | A主定位X、Z/Y柔顺；B支撑Z、X浮动；下鞋装调±8 mm独立于-Z30 mm释放动作 | 下垫当前对应link2；接触注册不等于已确认承压区域；不以2mm厚垫自动消除间隙 |
| A07 | 保持独立托持，逐站缓调下垫及上接触垫并测反力/压缩 | 上垫当前CAD对应link3名义采样相切区域，下垫对应link2；上垫释放+Z12 mm | 高保持组不是直接夹link2；依据实际壳体/刚度分流，不均分反力；壳体允许压力仍待确认 |
| A08 | 空载装被捕获锁销、Y导轨/载台、机械限位和Ø8 mm手动丝杆候选 | 两站Ø6×64 mm销轴/Ø12 mm俘获头分别向-X拔48 mm；核对销头、工具与防脱路径；独立锁销承载，不依赖丝杆/电机holding torque | 两站上下触点都撤开才可+Y180 mm；下鞋-Z30及上垫+Z12先行；未选电机或传感器型号 |
| A09 | 装两站锁销/上下触点/载台的开关支架及flag | 两套信号分别对应真实锁销、接触脱离和载台退出；半脱开/矛盾可识别 | 本轮只有几何接口与虚拟输入；行程开关动作不自动等于所有约束已释放 |
| A10 | 装真实根部连接器/背壳、固定线夹、护口和活动样段 | 接头锁紧、应力释放、出线方向、固定点和有效长度 | 未读厂家动态要求前保持HARNESS_PROXY_ONLY；线缆不能代替机械托持 |
| A11 | 后续台架在独立托持/卸载持续有效条件下手动复位→请求脱开→两销向-X各48 mm→上垫+Z12/下鞋-Z30→两载台+Y180 | 逐级记录两套确认、实际位移/间隙、支反力、线缆曲率/夹挤；不可跳过CONTACTS_RETRACTED阶段 | 本轮只执行离线状态机；真实首次试验仍待工装/输入；故障复位必须人工＋托持并返回保持态，不自动命令臂 |
| A12 | 待指定试验输入齐备，执行受控低速首动和异常状态台架试验 | q(t)、卸载/托持力、位移、接触力、退出信号、停机过程 | 与LOAD_CASES规定工况对应；独立托持能力和停止距离先确认 |
| A13 | 完成后恢复独立托持并按逆序卸载/拆装 | 先接管臂重量→卸保持预紧→松支承→拆线缆接口→松臂根；实测回差/永久变形 | 不在臂悬空时先松根部；缺陷回写候选参数/零件，记录受影响复检 |

## 保持、退出、首动的验收语义

流程为 `PARKED_HELD → RELEASE_REQUESTED → LATCH_OPEN_CONFIRMED → CONTACTS_RETRACTED_CONFIRMED → CARRIER_CLEAR_CONFIRMED → ARM_FIRST_MOTION_ALLOWED`。Y退出要求双锁销和两站上下触点均确认脱离；臂首动要求双退出、两套信号有效无矛盾、独立托持/卸载及人工复位有效，再有明确首动请求。[RELEASE_SEQUENCE](RELEASE_SEQUENCE.md)和[25场景结果](results/RELEASE_STATE_MACHINE.json)仅为已执行的纯离线逻辑验证，硬件输出始终false。

- 未完全脱开、单侧/部分释放、信号超时/矛盾：保持臂首动禁用，使用独立托持后检查，不靠增大驱动力强行脱开。
- 停电：记录锁止/滑台/支承/臂制动的实际状态；未有实测前不假定任一关节会保持。复位先由托持接管载荷，再卸预紧和按机械路径复位。
- 退出量：`s_required = s_clear_geometry + position_error + stop_overtravel + margin`；各项沿实际Y运动定义，未知项为null。当前采用先上垫+Z12/下鞋-Z30，再+Y180 mm的候选，旧160 mm保留历史；状态机行程确认不代替完整几何/误差/实物净空验证。
- 锁销初值反例：旧18 mm退出在载台首段Y运动中仍发生几何相交，见[R1几何反例](results/KEY_GEOMETRY_CHECK_R1_FINDINGS.json)；当前向-X48 mm对应名义轴向间隔8 mm，实配须另计误差和挠曲。离线状态机已验证旧18 mm即使给出open信号，也不能获得Y或臂许可。
- 接触验收：支承与承载面对偶按局部接触判据检查；禁止接触对按几何/制造＋装配＋回差/控制＋挠曲＋适用热误差＋余量检查，未知项不置0。

## P01–P06与本轮交付对应

| 编号 | WP02实际工作入口 | 本轮状态 | 实物验收记录 |
|---|---|---|---|
| P01 | INPUT_AND_MEASUREMENT、MEASUREMENT_REGISTER；厂家固定commit的小件STEP/BOM逐项注册 | 厂家GitHub源已核查并缓存小文件；孔公差/承压/线缆动态字段未齐 | 根孔/基准、两站下link2和上link3接触依据、线缆/质量待测 |
| P02 | 本轮可编辑根板/桥/锚固、鞍座、滑台、连接器/线夹设计与CAD收据 | CAD执行由本包实际几何收据逐项记录，不由本表预填通过 | 实配孔/接触件NOT_FOR_MANUFACTURE，直至相应实配/设计输入核实 |
| P03 | 本文A01–A10；工具/安装/拆卸路径CAD检查 | 离线检查结果按实际记录引用 | 台架首装NOT_EXECUTED_PHYSICAL |
| P04 | release_state_machine.py、锁止/上下触点/滑台确认结构及扫掠检查 | 25/25合成逻辑场景满足预期，含旧18 mm反例拒绝；路径净空另读实际覆盖结果 | 首次释放/复位/故障台架NOT_EXECUTED_PHYSICAL；不将虚拟输入当有效实物信号 |
| P05 | 固定点/有效长度/线束代理与厂家BOM端型/长度 | 已取得XT30_2+2长度/端型；OD/动态限制未齐前HARNESS_PROXY_ONLY | 真实线缆动态样段NOT_EXECUTED_PHYSICAL |
| P06 | 本轮关键组合件版本/差异/测量回写清单 | 以关键组合件设计评审收口 | 未自动扩大为整星加工/采购/硬件操作 |

## V01–V13验收映射

| 编号 | 本轮离线范围 | 后续实物/扩展范围 | 当前结论口径 |
|---|---|---|---|
| V01 重建与装配 | 新件参数重建、孔/面/工具路径、STEP读回 | 孔/面实测与首件装入 | 离线结果逐件记录；不代替实配 |
| V02 布局 | OPEN_PARKING关键组合件完整性及接触配对 | 实物停放与线缆包络 | 不写紧凑发射收拢通过 |
| V03 运动 | 保持/退出/臂首动路径与覆盖矩阵 | 带真实线束的低速台架 | 有限采样只报SAMPLED_PATH_CHECK |
| V04 载荷 | 三类工况、力矩移轴、单位载荷柔度/敏感性候选 | 规定载荷、连接滑移、根部刚度与支反力量测 | 无输入/许用值时不写强度PASS |
| V05 释放 | 两销向-X48、上垫+Z12、下鞋-Z30、Y180 mm的顺序状态机；25离线场景 | 脱开/触点撤离/退出/半脱开/拒动/人工复位台架 | 逻辑场景通过不等于实物释放成功 |
| V06 线束 | 明确固定点/长度/连接器空间，代理路线检查 | 动态曲率/扭转/反力/寿命 | 供应商动态限制与实测缺项为null |
| V07 装入维护 | 本组合件螺钉/工具/连接器装入及拆卸 | 完整设备板/整星维护 | 超出当前范围项另列，不作通过 |
| V08 翼 | 仅把已有翼作为干涉背景/接口 | 实际翼动作须在独立托持接管后移开GSE并检查；翼铰链/线束/实物展开另包 | 本轮不证明翼部署/功率闭合 |
| V09 属性 | 源/零件身份与ONBOARD/GSE/代理分账 | 实物质量、重心、刚度、安装矩阵 | 数字质量与实测分别记录 |
| V10 末端 | F/T插入腕链及相机接口为并行候选 | 真实夹力/外参/传感器标定 | 未在本组合件上宣称已集成标定 |
| V11 具身闭环 | 仅定义相关接口/状态与记录字段 | 静止目标完整观测—动作闭环 | 本轮没有真实自主捕获 |
| V12 异常 | 已测unknown/一侧/超时/矛盾/失电/动作绕过/人工故障复位及许可撤销 | 受控故障注入与停止距离 | 合成故障验证不替代机械停止/传感器资格试验 |
| V13 环境 | 后续发射/运输、真空热、润滑材料/寿命输入列表 | 实际任务与供应件条件下环境试验 | GSE开放停放不能外推飞行合格 |

当前可先评审并制作的仅是**独立、不承受真实臂载荷的尺寸/工具/连接器样件**；材料与生产工艺决定的承载件须有实配、载荷和完整图纸依据。本轮仍持续完成详细候选，不将待测项转化为重复许可申请。

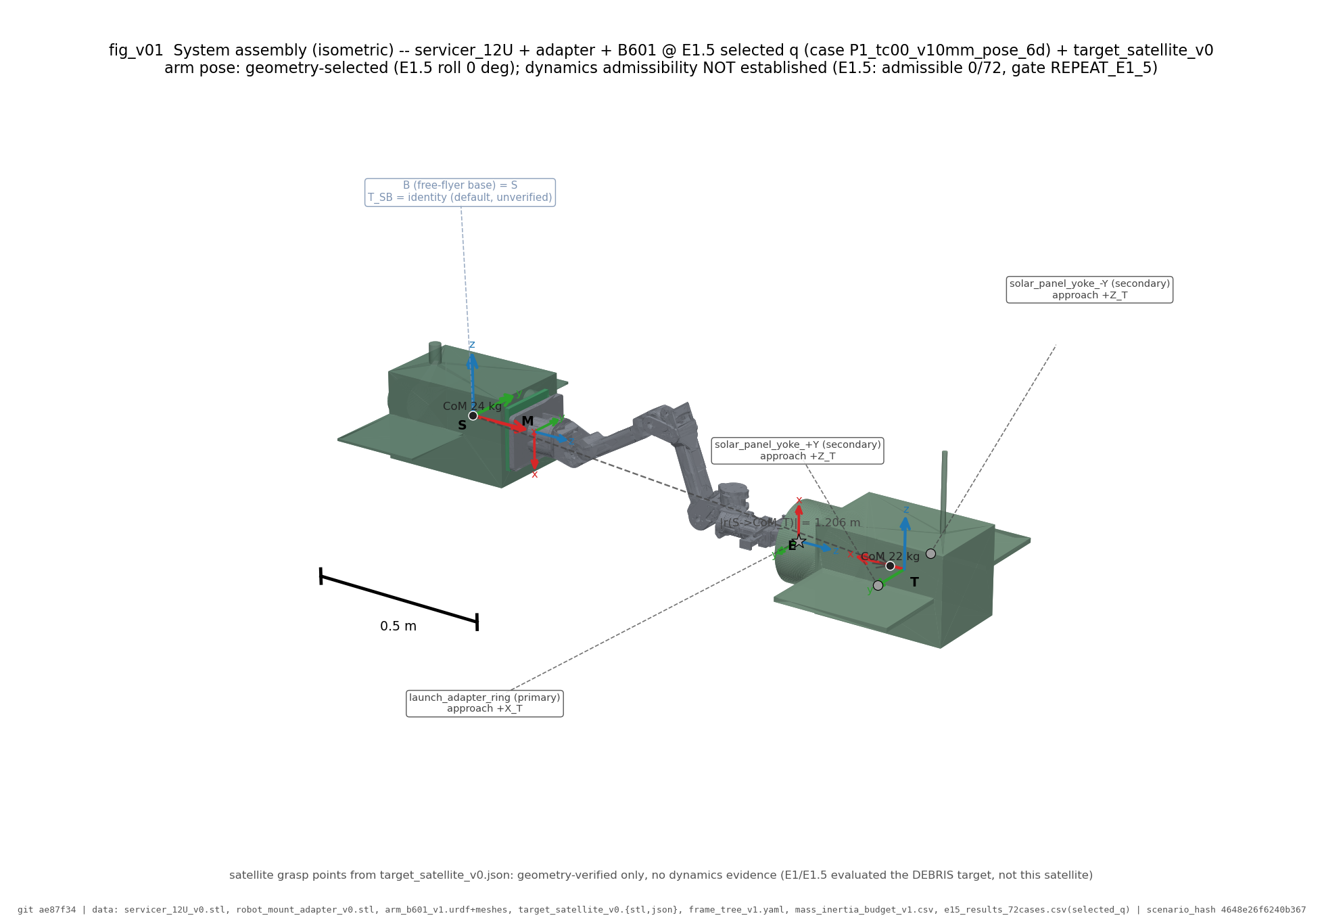
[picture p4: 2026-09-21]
40_evidence/artifacts/visualization/figures/fig_v01_system_assembly_isometric.png

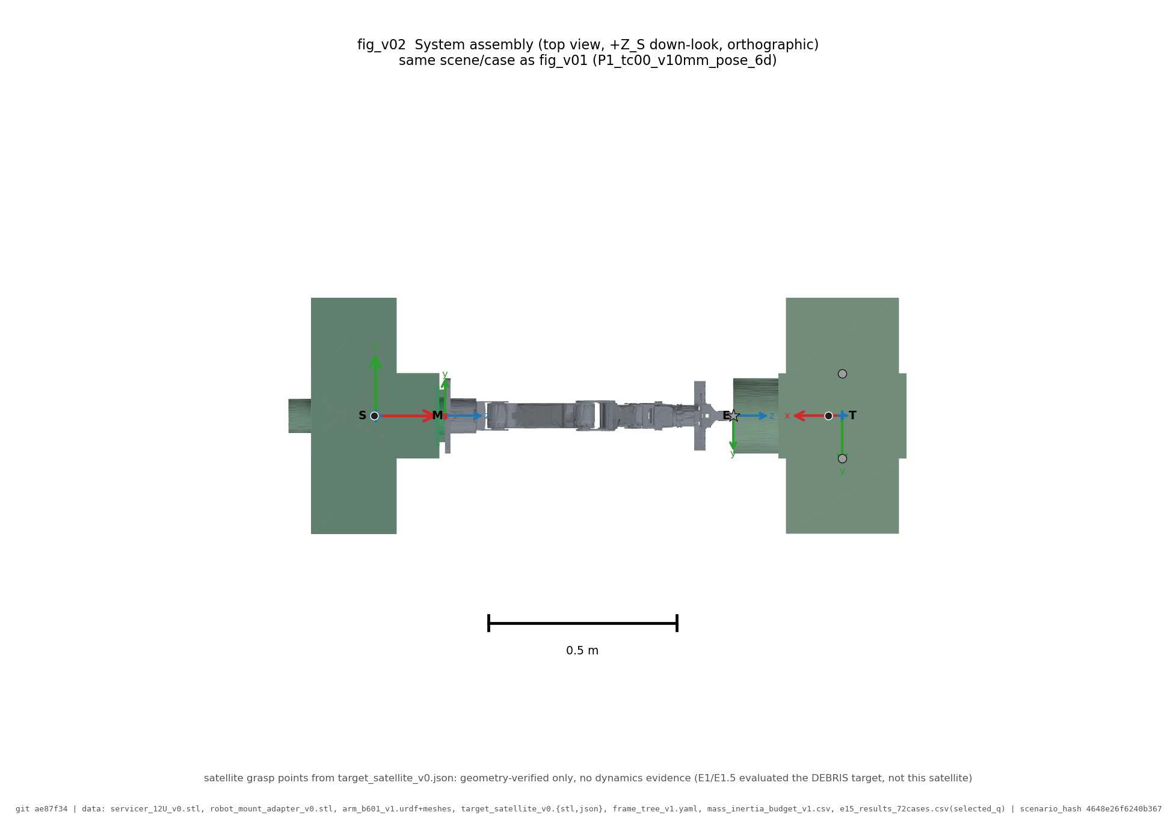
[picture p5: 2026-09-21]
40_evidence/artifacts/visualization/figures/fig_v02_system_assembly_top.png

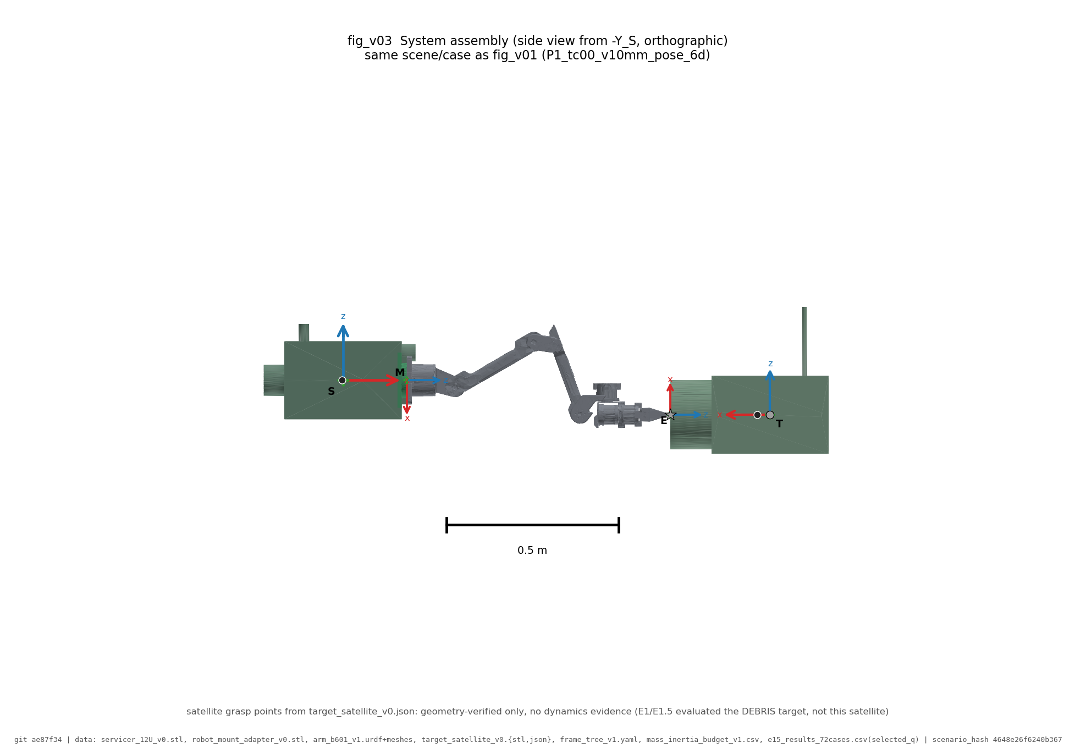
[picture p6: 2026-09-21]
40_evidence/artifacts/visualization/figures/fig_v03_system_assembly_side.png

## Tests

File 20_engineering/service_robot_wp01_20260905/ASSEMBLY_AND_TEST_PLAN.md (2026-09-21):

# WP01 后续零件化、装配与具身联调计划

日期：2026-09-05。对象：`WP01_ROOF_EXTERNAL_R1`，由本包 `design_parameters.json` 驱动的服务星/B601 候选。本文是本轮开始设计后的执行分解；下面所有尚未运行的检查与试验均为计划，不能据表格视为已通过。输入依据见 `DESIGN_INPUTS.md`，对偶接口依据见 `interface_requirements.csv`。

## 1. 先做一个真实可装的关键组合件

首件包含：代表性的框梁/端框段、臂根转接与承载桥、完整 B601 或与其实配接口一致的臂根件、两处可调支承、保持锁扣、释放件及确认传感器、真实臂根电缆和连接器。工作目标是确认臂能安装、支承能调到实际接触面、锁扣能保持并完全退出、手和工具能伸入、线束不妨碍释放与首段运动。

首件先在工装上独立装调，完成接口量测与低速动作；需要承载时，按明确载荷和工装能力另立试验工况。外观打印件可检查包络与装配路径，不能替代材料/连接强度试验。

| 工作项 | 必须产物 | 拿到什么结果后进入下一项 |
|---|---|---|
| P01 实配测量 | B601 根部孔/基准测量表；壳体可支承区域；线缆及插头样件记录 | 对偶面、孔型/深度、插拔方向与测量误差能标到图上 |
| P02 接口零件化 | 转接板/桥/框锚/鞍座/锁扣/导向件可编辑实体、尺寸图和标准件表 | 每个紧固件能装入并拧紧；每个基准/配合有公差目标 |
| P03 工装试装 | 实际装配顺序、工具清单、接触/间隙实测、整改照片 | 无不可达紧固点或被封死连接器；支承调整量覆盖实配偏差 |
| P04 释放动作 | 保持→指令→脱开确认→退出包络→初始展臂全过程记录 | 实测行程与反力能解释动作；断电/未完全脱开不会触发臂动作 |
| P05 真实线束 | 同固定点、同连接器下的全程形态、最小弯曲、端部反力/扭矩和磨擦记录 | 供应商限制与实测误差下仍满足；不满足则修改支架/余长并复测 |
| P06 收敛后放大 | 修订的整星总装、关键件图、接口表与问题关闭记录 | 实配修改已回写唯一参数源，后续主结构与设备板沿此版本设计 |

## 2. 分总成与整星装配顺序

| 序号 | 装配操作 | 当步必须检查 | 返修/拆卸要求 |
|---|---|---|---|
| A01 | 工装定位后端接口和主框梁，装端框/横梁 | S 基准、对角/平面度、框梁对偶面、通孔/螺纹及工具位置 | 开放至少一个设备装入面；定位销能按规定方向退出 |
| A02 | 安装承载桥、臂根转接及其定位/紧固件 | 载荷能沿实体/紧固连接传到主框架；Stage A 环/B 槽按嵌套对偶装入；基准转换与装后孔位 | 臂根紧固和力矩工具不被设备板封住 |
| A03 | 装电池/电源、计算机/驱动、姿控设备板及热连接 | 设备实选尺寸、底脚、热垫厚度/压紧、接插件朝向、维护拔出 | 首装前做纸样或实体包络插入；可拆板不牵拉固定干线 |
| A04 | 布置母线固定干线、分支与接地连接 | 连通/标识、防呆、应力释放、穿舱边缘、防磨、连接器锁紧 | 能断开分总成，不需剪线才能拆设备 |
| A05 | 支撑 B601 后安装根部并记录关节零位 | 候选 frame 为 [90,0,125.15] mm；名义 BRep 接触面 z=127.555 mm，见 [接口几何收据](results/INTERFACE_GEOMETRY.json)；实物注册、紧固程序、实际安装矩阵与线束承力另测 | 工装托持臂后才松根部；保留独立拆臂路径；不把 frame 原点当接触面 |
| A06 | 安装末端工具、F/T、相机及腕部线束 | TCP/相机/F/T 基准，线缆朝向，夹爪全行程与标定靶可达 | 末端传感器单独可更换；拆后按基准或重标定恢复 |
| A07 | 调整鞍座并装保持/释放机构、确认传感器 | 接触点/垫厚、自由度分配、预紧、释放退出量、手动复位 | 可独立调整/换垫；地面复位不需拆主结构 |
| A08 | 装两侧翼根/翼、保持件、翼根服务环 | 铰链轴、锁止、两翼线束与臂首动包络 | 翼可单独拆卸，释放器更换与插头可达 |
| A09 | 完整展开序列检查后装覆盖件 | 禁止接触区、散热/视场/维护开口、覆盖件与活动线束 | 可打开检查保养；封闭前留紧固、线束及序号记录 |
| A10 | 实装称重、零位/外参标定及数字模型更新 | BOM/序列号/修订一致；总质量、CG、关节方向、TCP与视觉外参 | 任何影响质量/安装的返修触发对应测量/标定更新 |

紧固规格、拧紧力矩、润滑/防松、螺纹啮合长度和材料许用值由实选紧固件与载荷计算确定。表中的“检查”不是提供未经依据的通用力矩值。名义 BRep 基座承载底面局部 z=2.405 mm，而 accepted STL 基座 bbox 从 z=0 起；CAD 的同原点接触结果不能替代 BRep/STL/实物基准注册。

## 3. 检查与试验矩阵

每项记录包含：配置 ID、部件/仪器序列号、参数/模型版本、实测数据及误差、明确的合格判据、异常与整改。未给定阈值的项目先输出要求及测量方法，不用默认零值判定。

| 编号 | 目的/工况 | 方法与输出 | 判据的来源/表达 |
|---|---|---|---|
| V01 | 可重建、可装配 | 参数改变后重建；对偶孔/安装面、装入路径、工具实体检查；STEP 读回 | 单位/坐标一致，部件不丢失；计划接口随动；STEP 读回仅证明导出可读 |
| V02 | 完整收拢布局 | 含臂掌指、转接、支承、保持器、连接器、电缆、翼与设备的尺寸和干涉表 | 采用本候选包络；正常接触列允许表；未授权穿透单独整改，不把低体积穿透自动忽略 |
| V03 | 释放与连续运动 | 固定根部变换下逐段检查：保持、脱开、初始展臂、翼展开、工作；必要时自适应加密 | 净间隙 ≥ 公差/装配误差 + 控制/挠曲误差 + 设计余量；各项来自实测/分析，不能只看关键帧 |
| V04 | 支承/根部承载 | 展开反力与收拢支承工况分别建模；孔边/接触/滑移/紧固与刚度计算，再做组合件载荷试验 | 载荷向量/谱、许用值、温度、紧固预紧及分流模型均明确；不把目标质量乘地面重力当在轨抓持载荷 |
| V05 | 保持与释放 | 量测接触预紧、锁扣位移、释放时间/反力；逐次复位；拒动/部分脱开/失电情况 | 行程足以退出最不利包络；确认信号与真实机械状态一致；循环次数/释放限值由实选机构寿命要求给出 |
| V06 | 臂与翼线束 | 真实样段在各关节/翼根循环；弯曲/扭转、余長、端部反力、磨擦、夹挤及连接器受力记录 | 不超过供应商动态限制；连接器不承担非设计拉力；有效长度/固定点与 CAD 相同 |
| V07 | 内部装入与维护 | 实选设备或尺寸一致的插入样件试装，含插头/扳手/抽出通道 | 不靠临时移走不可拆结构才装入；维护动作有确定路径；热界面/线缆不被动作破坏 |
| V08 | 翼部署 | 翼铰链/保持/锁止和线束一起检查；评估臂先、翼先两种顺序并选定 | 同一配置下臂翼运动与线束空间成立；实际力矩/锁止/阻尼满足定义工况 |
| V09 | 数字属性一致 | 称重与质量预算对账；CG 测量；姿态相关质量惯量重算；碰撞几何绑定 | 每个实体仅计一次；惯量明确参考点、轴向和配置；不得把旧整星预算块叠加到新设备 BOM |
| V10 | 感知与末端 | 夹爪行程/夹持力、F/T 零偏/安装刚度、相机视场/遮挡和外参标定 | 阈值由实选传感器、目标接口及任务误差预算确定；关节/相机/TCP时间和坐标可对应 |
| V11 | 具身最小闭环 | 在固定/卸载条件执行静止目标识别→规划→约束检查→接近→抓持→反馈→释放 | 记录定位误差、接触峰值、持稳/滑移和完成率；控制限值来自本实装硬件；不外推自由漂浮捕获 |
| V12 | 异常停止 | 目标丢失、反馈过期、受阻、力阈值、未脱开、断电/失联等注入 | 机械状态与控制动作可解释；停止距离/停止力实测；未确认释放时不允许移动受约束臂 |
| V13 | 后续环境适应性 | 实际任务确定后制定振动/冲击、热真空、润滑/材料、寿命试验 | 条件与判据来自任务/供应件和分析；本轮不声称已经获得飞行资格 |

## 4. 必须保留的设计记录

- **接口尺寸表**：孔中心、定位面、法向、孔/轴类型、配合/公差、螺纹深度、紧固件插入和工具方向。
- **动作定义**：固定的 `T_S_A0`、每个状态的六轴角/夹爪开度/翼角、释放件状态、同一套线束固定点；关键帧与连续路径结果分别保存。
- **装配图/BOM**：原生零件引用、材料/工艺、数量、质量来源、标准件、采购型号、修订、允许代用及对验证的影响。
- **试装记录**：每次改件的原因、实測与设计差异、影响到的接口、图纸修改、需要重做的检查。
- **具身交接**：视觉/碰撞几何、关节与驱动限制、安装矩阵、TCP/F/T/相机标定、实际质量/惯量、线束工作区及机构状态；全部指向同一实装版本。

## 5. 下一轮工作顺序

1. 接收本轮总体参数/STEP 检查结果，给每个接口分配真实对偶零件和固定基准；先明确臂根、支承、释放和线束。
2. 按 P01–P02 完成关键组合件零件化，同时补根部实配、电缆、末端与设备输入。
3. 先完成可装性和保持/释放试装，再进入负载、循环与全范围动作；实测不满足项直接改对应零件。
4. 在其基础上并行完成翼与内部设备，汇入唯一总装，输出全套工程图/BOM/工艺和整星装配记录。
5. 更新实装数字模型后执行 V10–V12；运动目标与自由漂浮场景作为后续扩大任务能力的独立验证。

来源限于 `DESIGN_INPUTS.md` 列明且本轮实际读取的项目文档与模型。本文没有新增标准符合性声明，也没有将规划项目记作已完成实体试验。

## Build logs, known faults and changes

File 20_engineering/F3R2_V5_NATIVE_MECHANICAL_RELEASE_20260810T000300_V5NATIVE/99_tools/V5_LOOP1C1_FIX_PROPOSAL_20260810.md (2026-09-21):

# V5 Loop1C1 — Final Report: error-5 root cause, patches, and the interference blocker

Date: 2026-08-11 (live-probe campaign on reserved session PID 87516, attach-only)
Scope honored: only `99_tools/F3R2_V5_NATIVE_LOOP1C1_GRIPPER_ASSEMBLY_ATTACH_ONLY.py` was patched; shared modules untouched; no receipt overwritten/deleted; protected baselines read-only; session left document-empty after every run.

---

## 1. Outcome

`--execute-assembly` now passes **mate creation (4 guide coincident + 2 advanced limit distance), configuration creation, per-configuration dimension drive, per-state transform/gap/rail-clearance gates**, and fails closed at exactly one remaining gate:

```
code: ASSEMBLY_INTERFERENCE_FAIL   (run 7, receipt V5_LOOP1C1_FAIL_20260811T0314..Z)
```

**The blocker is not an assembly defect — it is donor-inherited geometry.** The current contract gate demands zero cross-component positive-volume interference; the accepted donor geometry intrinsically carries palm↔finger and finger↔finger volumetric overlaps at every kinematic state. Proceeding requires a human/contract decision (see §5).

## 2. Final root cause of LIMIT_MATE_ADD_FAIL (error 5), proven live

1. **Guide coincident alignments rotated the fingers.** Production had `L_A=0, L_B=0, R_A=0, R_B=1`. On this SW2024 SP5 install, a coincident mate between the already-coincident parallel guide planes with alignment 0 flips the component to the 180°-rotated solution branch (probe v2: LEFT→rotY180, RIGHT→rotZ180 after guides).
2. rotZ180 flips the RIGHT limit face's true normal +Y→−Y, making it parallel to the palm's −Y face. The authored R limit mate `alignment=1` (correct for the design pose, where the normals are anti-parallel) then contradicts the rotations locked by the guides → `swAddMateError_OverDefinedAssembly (5)`. LEFT escaped because rotY180 keeps +Y normals. The earlier rounding patch (unrounded `LIMIT_MAX_MM`) fixed a real 2.0e-8 m latent defect but was not the cause.
3. Probe matrix (v2): in the rotated state, EVERY R variant fails (plain/limit, wide/strict range, flip, swapped selection) except align=0, which then yanks the finger off-design. Note: error 5 still leaves a created mate feature behind.
4. **Working recipe (probe v4/v5, all confirmed live):** all four guides at alignment 1 → both fingers keep identity rotation at ty=±71.5 mm; R limit = palm-first, align=1, flip=True; L limit = finger-first (swapped selection), align=0, flip=False; both created as PLAIN distance (upper=lower=0) and converted in place via `IDistanceMateFeatureData.ModifyDefinition` (IsAdvancedMate, min=0, max=base+71.5) — a direct limit create at the range boundary is rejected, and a negative Distance at create returns ErrorUnknown(0).
5. Per-config drive: only `SetSystemValue3(v, 3, VARIANT(VT_ARRAY|VT_BSTR,[name]))` actually stores per-config values here (probe v6); `swThisConfiguration` and plain-list variants silently no-op with status 0. Mate feature handles must be re-fetched AFTER `AddConfiguration2` — stale handles crossed OPEN↔HOLDING slots (probe v8). `GetSystemValue2(name)` readbacks lag one write on fresh handles → the production readback gate runs once over the full 8-cell table after a rebuild (probe v7 table + activation geometry all exact: OPEN/PREGRASP/CLOSED/HOLDING → ty ∓71.5/∓55/0/0).
6. `IMateEntity2.Reference` raises DISP_E_MEMBERNOTFOUND via the makepy static binding; late-bound dynamic dispatch returns the face (micro-probe, accessor A2, valid 807-byte persist refs).
7. Stale component handles after configuration switches read `Transform2` as zeros → `verify_state` re-resolves components per state.

## 3. Production patch inventory (Loop1C1 script only)

- `GUIDE_CONTRACTS`: all four guide alignments → `SW_ALIGN_ANTI (1)`.
- `LIMIT_CONTRACTS`: added per-side `flip`/`swap` (L: swap=True, flip=False, align=0; R: swap=False, flip=True, align=1).
- `add_advanced_limit_distance`: per-side selection order + flip; plain create; existing ModifyDefinition conversion retained; all fail-closed gates unchanged.
- `LIMIT_MAX_MM`: exact `base + 71.5` expressions (first patch, retained).
- `establish_configurations`: fresh feature re-resolution after config creation; typed-BSTR named sets; deferred full-table readback gate; per-side law `base + t` for BOTH sides (was `base − t` for L — measured wrong).
- `configuration_distance_values`: same law fix; readback via `GetSystemValue2(configuration)`.
- `verify_state`: re-resolve the 3 components after each configuration activation (stale handles read zeros).
- `mate_ledger`: mate-entity face reference via dynamic dispatch (A2).
- Comments updated to the measured laws and the true error-5 mechanism.

Verification of every stage by live probes (logs in `99_tools/probe_logs/`): R_LIMIT_MATRIX v2, ALIGN_SIGN v3/v4, DRIVE v5, CONFIG_DRIVE v6/v6b, TRUTH_TABLE v7/v8, MATE_ENTITY_REF, INTERFERENCE v9, DONOR_INHERITANCE v10, INTERFERENCE_BODIES v11.

## 4. The interference blocker — evidence

`verify_state` → `interference_fact` (TreatCoincidenceAsInterference=False, multibody internal included) fails on real volumetric overlaps (run-7 receipt + probe v9 per-state table):

| state | rows | total mm³ | max single mm³ |
|---|---|---|---|
| OPEN | 28 | 1267.42 | 435.91 (rail interface @ guide plane x≈−74.06, palm +Y end region) |
| PREGRASP | 16 | 780.11 | 259.38 |
| CLOSED | 39 | 350.20 | 79.53 (jaw contact shell, ~0.03 mm thick over the jaw face) |
| HOLDING | 39 | 350.20 | 79.53 |

**Donor-inheritance proof (probe v10):** the donor source part `B51_REF_gripper_detail_LINKLOCAL.SLDPRT` (57 bodies, LINK6_LOCAL, static arrangement = CLOSED state) contains **81 internal positive-volume interferences**, including:
- max row **79.527907 mm³** — bit-identical volume to the V5 CLOSED finger↔finger jaw shell;
- **16 rows of exactly 12.055338 mm³** — bit-identical volumes to the V5 CLOSED palm↔finger rows.

**Drive-sign hypothesis (W1) — tested and REFUTED (probes v9/v10/v11):**
- Overlaps occur at EVERY state, including CLOSED (travel 0, no drive influence): 39 rows / 350.20 mm³.
- The donor part — no mates, no drive at all — contains the identical CLOSED overlap set (volumes match to 6 decimals).
- At OPEN the measured jaw gap is exactly the authority 82.2284 mm and the opposed-transform gate passes, so the fingers are at the authority-correct pose; a wrong drive direction would move the jaw gap off authority.
- Body-level identification (v11): the dominant OPEN overlap (435.91 mm³) is `PALM_SOLID_09__...LINKLOCAL054` (palm detail body carrying the guide/limit faces) against the finger rail solids (`RIGHT_FINGER_SOLID_01__...LINKLOCAL`, `..._06__...016`, mirrored LEFT bodies); the CLOSED 12.055338 mm³ rows are `PALM_SOLID_09 (054)` / `PALM_SOLID_07 (050)` / `PALM_SOLID_08 (051)` against finger solids 016/028/033/043/044/046 etc.

Identical volumes at 6 decimals prove the Loop1C0 body copy was faithful and the overlaps pre-exist in the accepted donor geometry. The travel-dependent growth (12→259→435 mm³ as CLOSED→OPEN) is the same rail interface geometry articulated; the donor CAD was only ever mesh-checked (0.25 mm tessellation, minimum-distance witnesses) and never natively interference-checked (closure docs: `05_clearance/F3R2_NATIVE_INTERFERENCE_OUTCOME.json` records that native probing failed on this machine at the time).

**Consequence:** the zero-cross-component-interference gate is unsatisfiable with the accepted donor parts at authority-correct poses (jaw gap 82.2284/50.5026/0.0 and travel gates all pass). No assembly-side choice (mates, alignment, drive) can remove overlaps that live inside the parts.

## 5. Decision required (human/contract level — F3 NOT executed)

- **Option A (recommended): contract amendment.** Accept the donor-inherited contact-interface overlaps as documented design contact interfaces, evidenced by the v9/v10 tables (exact volumes/bboxes), while keeping the gate's teeth for *new* collisions: e.g., gate on "cross-component interference set equals the documented donor-inherited table" (frozen volume/bbox fingerprints per state). This changes the recorded contract — needs human sign-off.
- **Option B: part rework.** Trim the overlapping interface solids in the three native parts (new Loop1C0′), then re-derive guide/limit face contracts. Cascades: new part hashes → new Loop1C1 inputs; travel-clearance authority re-measurement. Heavy.
- **Option C: accept overlaps as-is into the release narrative** without a gate — NOT recommended (unbounded claim).

## 6. Rerun once decided

```bat
cd /d "F:\China Graduate Future Flight Vehicle Innovation Competition\20_engineering\F3R2_V5_NATIVE_MECHANICAL_RELEASE_20260810T000300_V5NATIVE"
G:\Windows_program_file\Anaconda\python.exe 99_tools\F3R2_V5_NATIVE_LOOP1C1_GRIPPER_ASSEMBLY_ATTACH_ONLY.py --execute-assembly
```

State is PENDING (no target/checkpoint exists), static audit authorizes execution. After the interference gate, the untested remainder is: `save_assembly` → `cold_verify` (read-only cold reopen, per-state re-verify, B-rep bbox, reference audit) → checkpoint + final receipt (`V5_LOOP1C1_NATIVE_GRIPPER_ASSEMBLY_PASS_MECHANICAL_MAINLINE_FREEZE_READY`).

## 7. Artifacts

- Patched script: `99_tools/F3R2_V5_NATIVE_LOOP1C1_GRIPPER_ASSEMBLY_ATTACH_ONLY.py` (py_compile clean; static audit `V5_LOOP1C1_STATIC_AUDIT_PASS_EXECUTION_AUTHORIZED`).
- Probes (attach-only, self-cleaning): `99_tools/V5_PROBE_LOOP1C1_{R_LIMIT_MATRIX,ALIGN_SIGN,DRIVE,CONFIG_DRIVE,TRUTH_TABLE,INTERFERENCE,DONOR_INHERITANCE}.py`, `V5_PROBE_MATE_ENTITY_REF.py`, `V5_SESSION_STATUS_CLEANUP.py`.
- Logs: `99_tools/probe_logs/*.log`.
- Fail receipts (write-once, newest last): `…T232652` (R limit error 5), `…T013206`/`…T014649` (config drive), `…T022149`/`…T024640` (transform contract), `…T032928` (Reference member), `…T0314*`/run-7 (interference).

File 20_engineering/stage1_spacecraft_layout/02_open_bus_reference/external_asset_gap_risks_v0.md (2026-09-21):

# 外部开源资产缺口风险登记 v0

> 文档角色：风险登记（资产缺口） ｜ 类型：process / risk
> 语言/主从：单语工作文档（中文）
> 版本：v0 ｜ 最后同步：2026-07-08
> 阶段原则：本轮仅新增。

## 为什么是新文件而不是改 `risk_register_v0.md`

`07_next_actions/risk_register_v0.md` **已存在**，含 R-001~R-014（Appendix B 未复核、rail keepout、质心超界、`T_SB` 未记录、材料未记、目标惯量缺失等布局/流程风险）。为遵守"不重写现有文件"，本轮把**开源资产缺口**单独登记为 `RA-`（Resource/Asset）前缀，并与既有 `R-` 交叉引用，避免编号冲突。后续如需并入主登记表，另行确认。

把"开源界确实没有的东西"从"资料没找够"转为**项目风险**——不再靠继续盲搜解决。

| 风险编号 | 风险 | 影响 | 证据/触发 | 处理 | 关联既有风险 | 优先级 | 状态 |
|---|---|---|---|---|---|---|---|
| RA-001 | 无 300–500kg 级服务星整星制造 CAD | 整星几何无法直接引用 | OSAM-1/Restore-L/MEV 几何未公开；开源只到 CubeSat/微卫星量级 | 整星**自研布局**，开源仅作子系统级堆叠/接口参考；报告说明比例关系 | R-011（12U 与 300-500kg 混用） | P1 | open |
| RA-002 | 无制造级软捕获/合作对接环 CAD | 合作接口(Target-3)无现成可造几何 | IDSS 仅 ICD 文档；开源多为标记靶标+通用互连 | 用 IDSS 做接口包络，**自建对接环占位体**；标记用 AstraTag/AprilTag | R-008（抓取特征未定义） | P1 | open |
| RA-003 | 目标星/碎片无实测质量-惯量真值 | Stage 2 捕获动力学缺可信输入 | 开源多给几何；42/space_robot/SmallSatSim 惯量需自定义；MMT/RoBo6 只给翻滚率 | 建**质量惯量假设表**，标 shape_model + confidence，禁止写成实测 | R-014（目标惯量缺失）、R-013（材料未记） | P1 | open |
| RA-004 | 抓捕末端执行器无空间级制造 CAD | 末端方案只能停在地面级 | OpenGrab/LEAP/DexHand/Yale/OpenManipulator 均地面级，缺真空/热真空/辐射鉴定 | 只做**地面级概念**，不宣称空间级成熟；空间化改造列为未来工作 | R-005（安装座刚度/FEA 未来工作） | P1 | open |
| RA-005 | 许可风险资产可能污染交付 | 交付资产包合规风险 | 无 LICENSE / NC / GPL/AGPL / 需注册 资源占相当比例 | `license_gate_v0.md` 阻断非 A 类进入可用池；D 类不复制 | — | P0 | open |
| RA-006 | 非合作目标真实在轨图像稀缺 | 视觉 sim-to-real 域隙 | SPEED+/SHIRT/SPARK 多为合成或地面 HIL | 用 SPIN 定制渲染弥补；报告标注域隙来源 | — | P2 | open |
| RA-007 | 中文原生在轨服务开源稀缺 | 自主可控替代来源有限 | 可核实的仅清华 SpaceOctopus(可用)、space_robot(无许可) | 以 SpaceOctopus 为国内锚点；其余国际资源过闸门使用 | — | P2 | open |

## 与既有风险的关系

- **RA-003 收敛 R-014/R-013**：目标惯量与材料缺失，本质是"开源无实测惯量真值"的具体表现，处理动作一致（假设表 + confidence）。
- **RA-001 支撑 R-011**：正因无 300–500kg 整星 CAD，12U 展示模型与 300–500kg 概念平台必须显式区分，不得混用同一 CAD。
- **RA-004 延伸 R-005**：末端与安装座都归入"地面级、不宣称飞行成熟、FEA/鉴定列未来工作"。

> 这些风险的共同处置原则：**承认缺口 → 自研占位 + 标注置信度 → 不宣称超出证据的成熟度**，而不是无限继续检索。

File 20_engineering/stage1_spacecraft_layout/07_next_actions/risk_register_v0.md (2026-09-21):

# Stage 1-C Risk Register v0

| risk_id | risk | impact | trigger or evidence | mitigation | priority | status |
|---|---|---|---|---|---|---|
| R-001 | Appendix B drawing dimensions not manually reviewed | CAD envelope may use wrong dimensions | manual review table incomplete | complete Appendix B review before freezing CAD dimensions | P0 | open |
| R-002 | robot protrusion exceeds limit | deployment/reference compliance issue | folded robot or adapter protrudes beyond allowed envelope | move mount inward, revise adapter, or document demo-only constraint | P0 | open |
| R-003 | rail keepout invaded | rail/deployer interface conflict | adapter, camera, panel, or fastener overlaps keepout | add rail keepout overlay and redesign placement | P0 | open |
| R-004 | center of gravity out of range | layout may not support credible platform balance | mass CSV shows bus/robot imbalance | redistribute battery/RW/bus placeholders and update mass budget | P0 | open |
| R-005 | robot mount stiffness insufficient | ground demo vibration or pose error; weak dynamics assumptions | adapter too thin or long without reinforcement | add ribs/thickened plate and mark FEA/test as future work | P1 | open |
| R-006 | solar panel or antenna collision | failed deployment or blocked robot task | workspace envelope intersects deployable envelope | adjust panel hinge, robot pose, or keepout zone | P0 | open |
| R-007 | camera FOV occluded | target approach narrative and demo video weakened | robot link, panel, or antenna blocks FOV | relocate camera or adjust folded/pre-grasp pose | P0 | open |
| R-008 | target contact failure | capture scenario not credible | grasp feature unclear or non-grasp region contacted | define target grasp feature and pre-grasp pose | P1 | open |
| R-009 | ground demo vs on-orbit narrative confusion | competition report may overclaim flight readiness | wording mixes demo choreography with flight operations | label ground demo and on-orbit concept separately | P1 | open |
| R-010 | VLA miswritten as low-level controller | architecture claim becomes technically wrong | VLA output described as joint torque | state VLA only makes high-level task decisions | P0 | open |
| R-011 | 12U scaled model confused with 300-500 kg concept platform | report scale logic becomes inconsistent | same CAD called both CubeSat model and 300-500 kg platform | define 12U as display/verification model and 300-500 kg as concept extension | P1 | open |
| R-012 | `T_SB` not recorded before Stage 2 | GJM/RNS model cannot reproduce layout | adapter CAD lacks frame marker | require frame marker and transform export | P0 | open |
| R-013 | material and density not recorded | mass/inertia budget cannot be traced | CSV lacks material/source/confidence | fill source fields before mass property use | P1 | open |
| R-014 | target model inertia missing | Stage 2 capture scenario incomplete | target CSV rows blank | estimate target mass/CG/MOI from CAD or documented primitive | P2 | open |

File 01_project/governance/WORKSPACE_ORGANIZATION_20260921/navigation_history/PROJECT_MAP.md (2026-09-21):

# 项目总导航

更新日期：2026-09-21。本页负责工作入口、目录职责与历史范围；工程和科学结论仍以对应源文件及机器裁决为准。

当前工作围绕可装配、可参数化、可验证的服务星与 B601 机械设计，并保留论文复现所需的模型、输入和负结果。既有比赛截止日期不再决定当前机械工作的进度。

## 从这里开始

| 工作 | 入口 | 使用范围 |
|---|---|---|
| 查看当前硬件精简设计 | [硬件设计包](./20_engineering/SERVICE_STAR_HARDWARE_COMPACT_20260921/README.md) | 以R6H后续集成总装为机械入口，电气线束、能源热控和推进主文件独立整理；原件保留 |
| 查看上游完整机械基线 | [WP03 设计包](./20_engineering/service_robot_wp03_spacecraft_body_r1/README.md) | 完整 B601、星体、双翼、随星保持器与设备接口的上游来源；不替代当前R6H |
| 接续机械装配与整改 | [装配程序](./20_engineering/service_robot_wp03_spacecraft_body_r1/ASSEMBLY_SEQUENCE.md)、[集成报告](./20_engineering/service_robot_wp03_spacecraft_body_r1/INTEGRATION_REPORT.md) | 区分已建几何、已有检查及待完成的选型、连接与实物试验 |
| 查看本轮整理与后续动作 | [CURRENT_candidate 工作入口](./01_project/competition/SERVICE_ROBOT_MECHANICAL_CONSOLIDATION_20260905/CURRENT_candidate.md) | 全项目整理和机械接续的会话入口；执行范围及结果以该入口与账本为准 |
| 检索文件、依赖、审阅和备份 | [统一 SQLite 目录](./01_project/competition/SERVICE_ROBOT_MECHANICAL_CONSOLIDATION_20260905/runs/loop0_20260905/screening/full_project_catalog.sqlite) | 文件目录及压缩快照，不替代原始工程证据 |
| 查阅跨域治理记录 | [current 治理入口](./01_project/current/README_CURRENT.md)、[发布指针](./01_project/current/CURRENT_RELEASE_POINTERS_V1.yaml) | 按其声明日期、对象和范围使用，文件名 CURRENT 本身不构成更新或工程合格证明 |

## 八个业务域

| 目录 | 职责 | 域入口 |
|---|---|---|
| [01_project/](./01_project/) | 项目治理、人工输入、协作、比赛历史及整理记录 | [README](./01_project/README.md) |
| [10_research/](./10_research/) | 研究问题、架构、论文与知识导航 | [README](./10_research/README.md) |
| [20_engineering/](./20_engineering/) | CAD、参数、接口、BOM 与机械系统设计 | [README](./20_engineering/README.md) |
| [30_simulation/](./30_simulation/) | 动力学、控制、安全与模块验证记录 | [README](./30_simulation/README.md) |
| [40_evidence/](./40_evidence/) | 图表、媒体、展示与证据快照 | [README](./40_evidence/README.md) |
| [50_literature/](./50_literature/) | 文献题录、原文、阅读卡与引用证据 | [README](./50_literature/README.md) |
| [70_tools/](./70_tools/) | 项目工具、索引、看板与可视化程序 | [README](./70_tools/README.md) |
| [80_third_party/](./80_third_party/) | 第三方代码、厂家来源与许可 | [README](./80_third_party/README.md) |

新增业务资产按职责进入上述域。根层保留导航与 Git/Agent/工具配置；现存非标准目录的处理与路径映射记入本轮账本，不根据目录名推定其已迁移或可删除。

## WP03 与 R2 分别查阅

**WP03 是保留的上游完整机械候选，当前硬件总装以 [R6H指针](./20_engineering/SERVICE_STAR_CORE_INSTALLATION_LATEST.json)为准。** WP03的[设计参数](./20_engineering/service_robot_wp03_spacecraft_body_r1/design_parameters.json)、[几何检查](./20_engineering/service_robot_wp03_spacecraft_body_r1/results/GEOMETRY_CHECK.json)、[路径检查](./20_engineering/service_robot_wp03_spacecraft_body_r1/results/INTEGRATE_CHECKS.json)和[质量惯量摘要](./20_engineering/service_robot_wp03_spacecraft_body_r1/results/DYNAMICS_SUMMARY_ZH.md)分别声明原对象与范围。静态非臂检查不覆盖完整连续动作；已分配数字质量不等于实测完整飞行质量。

**R2 原机器结论独立保留。** [MECHANICAL_ENGINEERING_RELEASE_R2](./20_engineering/MECHANICAL_ENGINEERING_RELEASE_R2/)的[原终裁](./20_engineering/MECHANICAL_ENGINEERING_RELEASE_R2/00_RELEASE_GATE.json)记录 Gate A 未通过、内部阻断已登记及无发布信用，`review_status=PENDING_OWNER_REVIEW`、`next_stage_authorized=false`。这些结论属于该 R2 发布包，不因 WP03 或文件整理而改写，也不自动转移到另一构型。

WP03 实际读取的 [WP01](./20_engineering/service_robot_wp01_20260905/)和[WP02](./20_engineering/service_robot_wp02_20260905/)仍有上游依赖职责。旧 30 mm 释放失败、源拓扑缺陷、厂家来源和冻结输入按自身证据身份保留与使用，不能按日期或相似名称判为无用。

## 研究与协作

- [研究知识入口](./10_research/knowledge_base/README.md)用于查找现有证据；[文献主清单](./50_literature/references/manifest.yaml)用于定位论文来源。
- 仿真与控制结论回到各模块原始裁决和声明工况。整理目录、生成展示或重建文件本身不新增科学结论。
- [AGENTS.md](./AGENTS.md)和[CLAUDE.md](./CLAUDE.md)保留客户端协作约定；历史阶段状态应结合日期、对象与最新用户任务理解。

## 历史内容已合并，旧文件已移出根目录

| 内容 | 现在的位置 | 本轮实际处理 |
|---|---|---|
| 旧启动指南、状态总结与入驻说明 | [历史综述](./01_project/competition/archive/ROOT_HISTORY_20260729_20260810.md) | 17 份 Markdown 合为一份，原文件已删除；保留源到段落映射 |
| 原 knowledge 两份方法笔记 | [结构与仿真资产方法](./10_research/knowledge_base/spacecraft_mechanical_design/legacy_structure_methods_20260728.md) | 两份合为一份，原文件已删除 |
| 原 structure 的合同和结构说明 | [结构历史材料](./20_engineering/system_design/legacy_root_structure/) | 8 件独有文件原字节归档 |
| 根级 F3R2 脚本 | [历史工具目录](./70_tools/legacy_f3r2_root_scripts/) | 9 个 Python 与 1 个 PowerShell 移入工具域；消费路径已修正 |
| 原 90_competition_closeout | [历史收尾记录](./01_project/competition/archive/90_competition_closeout/) | 55 件记录保留原字节 |
| 入驻包独有图示与 JSON | [2026-07-29 入驻快照](./01_project/competition/archive/onboarding_20260729/) | 3 件保留归档 |
| 根 B51 压缩包与展开副本 | [规范授权来源](./20_engineering/cad/B5_1R1_B601_interface_native_rework_candidate/00_BASELINE/AUTHORIZATION_PACKAGE/) | 删除根部重复 ZIP 及 3 份展开副本，验证程序读取保留副本 |
| 旧模型优先级 YAML | [2026-08-08 历史快照](./01_project/current/archive/PROJECT_MODEL_TRUTH_HIERARCHY_20260808.yaml) | 原值不变，旧消费者按归档路径读取 |

根目录现在保留八个业务域、必要的 Git/客户端配置，以及 PROJECT_MAP、AGENTS、CLAUDE 三份 Markdown。此次根部整理没有重跑或升级 CAD、仿真与科学裁决。

详细原路径→新位置、删除动作与修改前原件保存在同一 SQLite：`root_layout_actions`、`reviews`、`snapshots`；恢复阶段为 `BEFORE_ROOT_PHYSICAL_CONSOLIDATION_20260906`。旧冻结记录仍声明当时的路径与哈希；它们不会因本次路径变更自动变成新版验证结果。

## 八域内部整理（2026-09-06）

已将 31 份重复说明归并、删除 2 份同字节报告与 159 个已核实可再生字节码，原始字节可恢复；本轮共删除 192 文件，新增 2 份合并文。各域现用入口见上表，详细合并去向、检查及未完成范围见 [整理工作入口](./01_project/competition/SERVICE_ROBOT_MECHANICAL_CONSOLIDATION_20260905/CURRENT_candidate.md)。

可访问文件均有处置记录；原生内容与未精读正文仍明确保留待审阅。12 个已空缓存目录被自动审批拒绝删除，未计入已清理目录。

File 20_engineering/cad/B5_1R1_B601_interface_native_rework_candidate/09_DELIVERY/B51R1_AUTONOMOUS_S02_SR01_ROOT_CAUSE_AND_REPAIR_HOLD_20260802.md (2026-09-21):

# B5.1R1 S02_SR01 冷重开失败根因与修复 HOLD

生成时间：2026-08-02T21:27:23.9192957+08:00

## 结论

`S02_SR01` 已完成对用户预先打开的唯一 SolidWorks 进程的附着，并成功以静默、只读方式打开固定 Master Skeleton。失败不再是进程启动或 ROT 超时，而是目标文件缺少必需的文档级自定义属性 `G1B_RECEIPT_SHA256`。

运行时证据为：

```text
failed_stage = TEN_REBUILD_READBACK_CYCLES
Get6("G1B_RECEIPT_SHA256", useCached=false) = 1
1 = swCustomInfoGetResult_NotPresent
save_api_call_count = 0
normal_document_close = true
normal_application_exit = true
```

Master Skeleton、Stage A、S01 current gate 及上一轮 S02 失败证据的 SHA、字节数和修改时间均未改变。

## 已确认的实现根因

`08_REVIEWS/B51R1_S01_MasterSkeletonFinalizer.cs` 第 188–196 行对八个文档属性调用了 `Set2`，没有先调用 `Add3`，也没有检查 `Set2` 返回值。

SOLIDWORKS API 的 `Set2` 参数是“现有自定义属性”的名称；本机 2024 interop 中 `swCustomInfoSetResult_NotPresent=1`。因此当模板中不存在这些属性时，`Set2` 不会创建属性。S02 的冷重开 `Get6` 返回 `swCustomInfoGetResult_NotPresent=1`，与该实现缺陷一致。

至少 `G1B_RECEIPT_SHA256` 已由运行时确认缺失。其余七个通过相同未检查 `Set2` 路径写入的属性也必须在修复后逐项验证，不能假定存在。

## 唯一可接受的修复路径

1. 不覆盖 `B51R1_MASTER_SKELETON_V2.SLDPRT`；从其创建新修订件 `B51R1_MASTER_SKELETON_V2_R1.SLDPRT`。
2. 对八个属性使用 `Add3(name, swCustomInfoText=30, value, swCustomPropertyReplaceValue=2)`。
3. 每次要求返回 `swCustomInfoAddResult_AddedOrChanged=0`。
4. 保存前逐项执行 `Get6(useCached=false)`，要求：result=2、WasResolved=true、LinkToProperty=false、raw/resolved 均与合同值完全一致。
5. 重新验证 21 项必需原生特征、44 项精确特征库存、3 个构型、0 实体、0 外部引用，以及所有坐标系/基准面/轴线。
6. 生成新的 S01 修订件 PASS receipt、supersession chain 与 current gate；旧文件和旧 PASS/HOLD 证据保持不变。
7. 再用独立新进程对新修订件执行 S02 的 10×3 冷重开验证。

重复运行当前 S02 不会修复缺失属性，因此禁止直接重试。

## 当前边界

```text
ledger = BLOCKED_S02_SR01_FAIL_CLOSED
consumed = 6
remaining = 14
next_session_authorized = false
SolidWorks process count = 0
H10 = 0/28
T005-A/B/C = NOT_RUN
```

下一步需要所有者一次性授权：一个 `S01_CR01` 属性修复槽，以及一个随后针对新修订件的 S02 冷重开槽。

当前不得进入 S03，也不得使用 `COMPLETE`、`MANUFACTURING_READY`、`FLIGHT_READY` 或 `LAUNCH_QUALIFIED`。

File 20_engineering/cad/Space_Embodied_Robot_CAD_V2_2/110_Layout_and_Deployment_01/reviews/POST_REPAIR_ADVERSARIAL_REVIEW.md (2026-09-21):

# V22-LAYOUT-AND-DEPLOYMENT-01 post-repair adversarial review

Independent disposition:

```text
OVERALL = ACCEPT_ISOLATED_STAGING_WITH_ENGINEERING_HOLDS
ORIGINAL_5_FAILS = 5 CLOSED / 0 OPEN
ADVERSARIAL_CHECKS = 20 PASS / 9 HOLD / 0 FAIL
SIX_GATES = 5 ACCEPT / 0 REVISE / 1 HOLD
CANONICAL_TOP_WRITE = NO
STRUCTURAL_RELEASE = NO
GLOBAL_COLLISION_RELEASE = NO
NATIVE_CONFIGURATION_RELEASE = NO
```

This acceptance is limited to an isolated STEP-first layout staging package,
five diagnostic geometry entrypoints, and two manifest-only state
entrypoints. It is not a flight-mechanism, structural, global-clearance, mass,
BOM, or native SolidWorks release.

## Current evidence set reviewed

- Current source:
  - `staging/layout_staging.py`;
  - `solar/solar_deployment_test_rig.py`;
  - `arm_stow/arm_stow_layout.py`.
- Current contracts:
  - `design/layout_decision_contract.json`;
  - `design/state_policy.json`;
  - `solar/solar_deployment_contract.json`;
  - `arm_stow/interface_claim_registry.json`.
- Current STEP:
  - primary `staging/layout_staging.step`;
  - all five `state_*.step` entrypoints;
  - repaired ARM-STOW STEP;
  - repaired solar sampled-sweep STEP.
- Current machine evidence:
  - `validation/staging_validation.json`, producer tally
    `12 PASS / 5 HOLD / 0 FAIL`, SHA-256
    `18a24b5c58eccb1f9d70f2aa6df38b16a6da948adb13d0ec3861499e436b40ee`;
  - `CURRENT_SUBSYSTEM_CONTRACT_HASH_LOCK = PASS`: the layout-decision
    contract's expected solar hash `a35cef0a...` and ARM-STOW hash
    `5be0bfad...` each equal the current artifact hash;
  - repaired ARM-STOW evidence, `15 PASS / 0 FAIL`;
  - repaired solar evidence, `26 PASS / 0 FAIL`.
- Latest post-repair snapshot packet stamped `20260726T142704Z`.
- Read-only accepted baseline hashes.

Current key hashes:

| Artifact | SHA-256 |
|---|---|
| Canonical V2.2 top | `3b55edb85b460ecbc23eec55b99ff83506c33e0f4cecdb0375babc7b0d50cfb9` |
| Prior mechanical continuation STEP | `c844c07177daf7e7b96d332d5060cfcbffe2c5989ded04602f9ec0dffd7c4b42` |
| Accepted B601 URDF | `1bc2b7483cd8025d08ba6eadfd9e1f3b0477121714e7cf4ddc1794d9e471c164` |
| q0 conservative-box evidence | `fe16f3b8460574c281351e22f97e51843bac918608443ef91041b6194aff2d8b` |
| Solar contract | `a35cef0a358b56fd32b5fcb63d3cefa2aa9ea988d1f812d48ca57b8aece371f6` |
| ARM-STOW contract | `5be0bfad416af6ebece0744b43f6abb99a44da1afe1f649e7ee3eb49e2cd74c4` |
| ARM-STOW STEP | `539dae5b45e179a8aa5390f32b91fbb5cc7d2af32de11ce4965535ad35878362` |
| Solar sampled-sweep STEP | `23610932784a48cc5b7f5edc724209eb36433ccca91772efa52f82a84473be3b` |
| Primary staging STEP | `6856f339aa9e4925cbb619e8da5793e3c77b1fed732b41f517163fd186b6f426` |

The current layout-decision contract records the current solar and ARM
contract hashes. The repaired ARM Markdown, JSON selector evidence, machine
validation and STEP all agree on hash `539dae...`, width `226.3 mm`, and
main-saddle-to-forward-crossbeam placement.

## Closure of the original five FAILs

| Original failure | Post-repair result | Evidence-backed ruling |
|---|---:|---|
| `F01_DEPLOYED_TIP_INTERFACE` | **CLOSED** | The staging contract explicitly selects the physically generated `310.00 mm` endpoint and retires `313.15 mm` for isolated staging. Interface ratification remains HOLD; the value is no longer misrepresented as preserved. |
| `F02_ARM_LOCAL_TO_CS_S_TRANSFORM` | **CLOSED** | The current contract defines identity rotation and `T=[0,0,119.15] mm`; all four local pad lower faces map to `CS_S Z=113.15 mm`. This is accepted for isolated staging only and remains interface-ratification HOLD. |
| `F03_ARM_SUPPORT_STATION_SEMANTICS` | **CLOSED** | Main-saddle brackets are now in the forward range (`X=[51,79]` inside `[40,90]`); wrist brackets are aft (`X=[-144,-116]` inside `[-150,-110]`). Selector alignment `#o1.1.11.f5 -> #o1.1.1.f6` is zero-translation against the forward crossbeam. |
| `F04_ARM_PHYSICAL_Y_PACKAGING` | **CLOSED** | Maximum physical ARM-STOW `|Y|` is now exactly `113.15 mm`; the repaired STEP bounds are `Y=[-113.15,+113.15]`. |
| `F05_ASYMMETRIC_FAILURE_POSES` | **CLOSED** | Separate state STEP labels and bounds substantiate `L_FAIL=(0,90)` and `R_FAIL=(90,0)`. The two top-view snapshots show opposite deployed sides. |

Closure means the prior blocking counterexample no longer applies. It does
not upgrade the associated interfaces or mechanism to flight authority.

## Independent check matrix

| ID | Status | Adversarial finding |
|---|---:|---|
| `P01_ACCEPTED_BASELINE_HASHES` | **PASS** | Canonical top, prior continuation STEP, accepted URDF and q0 evidence all match their registered hashes. |
| `P02_COMPOSED_CONTRACT_HASH_LOCK` | **PASS** | Current solar and ARM contract hashes match the current layout-decision source lock. |
| `P03_ARM_STEP_EVIDENCE_SYNC` | **PASS** | ARM STEP, validation JSON, selector JSON and Markdown agree on hash `539dae...`, 150 positive-volume solids and `Y=±113.15`. |
| `P04_SOLAR_STEP_EVIDENCE_SYNC` | **PASS** | Solar sampled-sweep hash `236109...` matches the repaired validation summary; producer result is `26 PASS / 0 FAIL`. |
| `P05_310_MM_DECISION_EXPLICIT` | **PASS** | `310.00 mm` is the only selected staging endpoint; `313.15 mm` is not silently claimed. |
| `P06_NUMERIC_CS_S_MAPPING` | **PASS** | Signed axes, identity rotation and translation `[0,0,119.15]` are machine readable and pad placement is numerically checked. |
| `P07_ARM_STATION_SEMANTICS` | **PASS** | Main saddle is forward and wrist is aft in source, contract and selector evidence. |
| `P08_ARM_Y_CONTAINMENT` | **PASS** | All physical pads and the complete repaired ARM STEP stay within the current `226.3 mm` Y package. |
| `P09_ASYMMETRIC_SOLAR_GENERATION` | **PASS** | Independent left/right angles and distinct L/R failure STEP entrypoints exist. |
| `P10_FIVE_STEP_ENTRYPOINTS_REOPEN` | **PASS** | STOWED, DEPLOYED_NOMINAL, DEPLOY_FAILED_BOTH, L_FAIL and R_FAIL reopen with 280 or 290 positive-volume solids. |
| `P11_STATE_REPRESENTATION_FAIL_CLOSED` | **PASS** | STOWED contains no substituted q0 arm and is labelled HIFI-absent; the other four geometry states contain the q0 conservative proxy and no HIFI representation. |
| `P12_PARTIAL_SERVICE_NO_BINDING` | **PASS** | `PARTIAL` and `SERVICE` have null bindings and no corresponding STEP files; diagnostic angles do not define PARTIAL. |
| `P13_STOWED_POCKET_IDEAL_GEOMETRY` | **PASS** | At 0 degrees the represented moving solar groups have no positive-volume intersection with the revised primary structure. This is ideal-geometry evidence only. |
| `P14_NEGATIVE_INPUT_PRESERVED` | **PASS** | The pre-pocket model still reproduces 44 positive intersection pairs, 22 per side; the repair did not erase the negative input result. |
| `P15_ARM_SUPPORT_CONTINUOUS_LOWER_BOUND` | **PASS** | For represented rigid solar geometry versus listed physical ARM supports, the 1-degree grid minimum `18.7781 mm` minus the `1.74553 mm` motion bound gives `17.03258 mm > 0`, bilaterally. |
| `P16_Q0_CONTINUOUS_LOWER_BOUND` | **PASS** | For represented rigid solar geometry versus accepted-URDF-derived q0 AABB proxies, the scoped continuous lower bound is `131.18890 mm`, bilaterally. |
| `P17_LIPSCHITZ_BOUND_FORM` | **PASS** | With maximum radius `200.02250 mm` and maximum unsampled angle `0.5 deg`, `R*delta_theta=1.74553 mm` is a conservative rigid-rotation displacement bound for the represented set. |
| `P18_STAR_TRACKER_CONFLICT_WITNESS` | **PASS** | The old top-centre star-tracker envelope remains a non-physical conflict witness intersecting the aft crossbeam by exactly `5625 mm3`; it is not hidden as a successful relocation. |
| `P19_LATEST_SNAPSHOT_SEMANTICS` | **PASS** | Latest opposed staging views, STOWED view and L/R failure top views agree with the named scene semantics; no visual claim is used as structural or clearance proof. |
| `P20_AUTHORITY_EXCLUSIONS` | **PASS** | STEP mass is excluded; accepted URDF mass remains `4.695555949342986 kg`; strength, stiffness, reliability, native configuration, BOM and flight qualification are explicitly excluded. |
| `H01_310_MM_INTERFACE_RATIFICATION` | **HOLD** | `310.00 mm` is selected only for isolated staging. A controlling spacecraft-interface ratification has not frozen it. |
| `H02_TOP_SUPPORT_INTERFACE` | **HOLD** | The `119.15 mm` translation establishes placement, not fasteners, insert geometry, local pressure, stiffness or load transfer into upper longerons. |
| `H03_POCKET_RESIDUAL_SECTION` | **HOLD** | The shallow pocket removes `6.65 mm` from a nominal `15 mm` outer member, leaving `8.35 mm`. Positive residual geometry is not strength, stiffness, buckling, fatigue or tolerance proof. |
| `H04_CASSETTE_EMBEDDED_OVERLAPS` | **HOLD** | The reported 50 positive overlaps comprise 44 against other staged primary solids and 6 against non-physical pocket datums; volumes range from `0.5625` to `20430 mm3`. Boolean overlap may express load-path intent or interference, but not a joint. |
| `H05_SOLAR_VERSUS_PRIMARY_CONTINUOUS_CLEARANCE` | **HOLD** | The integer grid finds no sampled interpenetration but reaches zero distance at 0 degrees. No positive global continuous lower bound or qualified tolerance exists. |
| `H06_HDRM_RELEASE_AND_HARNESS` | **HOLD** | HDRM selection, preload, release direction, shock path, latching, spring/stop loads and harness flex remain undefined. |
| `H07_PRE_CAPTURE_SERVICE_AND_GLOBAL_COLLISION` | **HOLD** | PRE_CAPTURE and SERVICE have no accepted joint vectors. No global arm workspace, full device set, flexible-body motion or service-access clearance was evaluated. |
| `H08_NATIVE_CONFIGURATION_BOM_MASS` | **HOLD** | Five separate STEP scenes are not SolidWorks configurations; there is no suppression, mate, BOM-exclusion or mass-property readback. |
| `H09_HIFI_CONTACT_DEVICE_AND_FLIGHT_CLOSURE` | **HOLD** | B601 HIFI/contact faces, actual top devices, FOV/RF/thermal/harness integration, manufacturing and flight qualification remain open. |

Independent tally: `20 PASS / 9 HOLD / 0 FAIL`.

## Shallow-pocket and load-path challenge

The pocket is an honest geometric repair, but its clearances are not an
engineering allowance:

- pocket X bounds exceed the panel by only `0.5 mm` at each end;
- the panel solid has `0.5 mm` nominal inboard Y margin;
- the cell witness has only `0.1 mm` nominal inboard Y margin;
- some root/top boundaries are coincident, producing the observed zero
  distance.

The `8.35 mm` residual width is one derived cross-section result; the model
does not prove minimum section over every cut member or structural
connectivity after subtraction. Likewise, the 50 overlap records are not 50
qualified attachments. Six involve non-physical datum witnesses, and all
remaining intersections still lack fastener, weld, bonded-joint, contact,
material and load definitions.

Therefore:

```text
POCKET_GEOMETRY = ACCEPT_LAYOUT_ONLY
CASSETTE_LOADPATH_INTENT = PRESENT
CASSETTE_STRUCTURAL_CLOSURE = HOLD
```

## Continuous-bound challenge

The 1-degree plus Lipschitz argument is valid for the represented rigid moving
solar group against the exact listed static proxy sets:

```text
d_continuous >= d_grid_min - R * 0.5deg_in_radians
```

It supports the two scoped positive lower bounds reported above. It does not
cover:

- revised primary structure, whose sampled minimum is zero;
- manufacturing and joint tolerances;
- hinge-axis error, panel flexibility, modal response or latch rebound;
- uninstantiated devices, harness loops, HDRM release hardware or B601 HIFI;
- PRE_CAPTURE, SERVICE or arbitrary arm workspace.

Thus the scoped arm-support and q0 checks pass, while global continuous
collision clearance remains HOLD.

## Seven-state ruling

| State | Post-repair ruling |
|---|---|
| `STOWED` | **Geometry entry exists, status HOLD.** It represents solar 0/0 and physical support layout but intentionally contains no q0 substitute and no unavailable HIFI arm. |
| `DEPLOYED_NOMINAL` | **Diagnostic geometry entry accepted:** solar 90/90 plus q0 conservative proxy. |
| `DEPLOY_FAILED_BOTH` | **Diagnostic geometry entry accepted:** solar 0/0 plus q0 conservative proxy. |
| `L_FAIL` | **Diagnostic geometry entry accepted:** left 0/right 90 plus q0 conservative proxy. |
| `R_FAIL` | **Diagnostic geometry entry accepted:** left 90/right 0 plus q0 conservative proxy. |
| `PARTIAL` | **Manifest only; no geometry binding.** Angle remains UNKNOWN. |
| `SERVICE` | **Manifest only; no geometry binding.** Human ratification and access sequence remain absent. |

These are five files plus two manifest-only entries, not seven native
SolidWorks configurations.

## Six-gate final decision

| Gate | Decision | Exact release boundary |
|---|---:|---|
| `SOLAR-LAYOUT-TRADE-01` | **ACCEPT** | Recessed lower book-fold is accepted for isolated staging at the actual 310 mm endpoint; controlling interface ratification remains HOLD. |
| `SOLAR-CASSETTE-01` | **HOLD** | Pocket and embedded overlap evidence establish layout/load-path intent only; residual-section, internal-volume, joint and tolerance closure are absent. |
| `SOLAR-KINEMATIC-01` | **ACCEPT** | Discrete, asymmetric and scoped rigid-body continuous-bound diagnostics are accepted. Global solar-to-platform clearance and mechanism reliability remain HOLD. |
| `ARM-STOW-LAYOUT-02` | **ACCEPT** | Corrected stations, platform Y containment and explicit CS_S staging placement are accepted as layout. Structure, attachment and contact qualification remain HOLD. |
| `ARM-SOLAR-CLEARANCE-01` | **ACCEPT** | Accepted only for represented solar versus physical support and q0 proxy sets under the stated rigid-body bound. PRE_CAPTURE, SERVICE and global collision remain HOLD. |
| `LAYOUT-STAGING-ASSEMBLY-01` | **ACCEPT** | Five isolated STEP entrypoints plus two null-bound manifest entries are accepted. Native configurations, BOM, mass and canonical-top integration remain HOLD/not authorised. |

Gate tally: `5 ACCEPT / 0 REVISE / 1 HOLD`.

## Final adversarial verdict

The repair is sufficient to continue into the next isolated mechanical-design
iteration. It is not sufficient to:

- release cassette or top-support structure;
- claim a flight-clear deployment mechanism;
- claim arbitrary arm/solar/device collision safety;
- define PARTIAL, PRE_CAPTURE or SERVICE geometry;
- claim native SolidWorks configuration, BOM or mass closure;
- write the canonical V2.2 top.

The next evidence gate should address pocket/cassette structural and tolerance
closure, then add accepted PRE_CAPTURE geometry and real-device integration
before expanding the collision claim.

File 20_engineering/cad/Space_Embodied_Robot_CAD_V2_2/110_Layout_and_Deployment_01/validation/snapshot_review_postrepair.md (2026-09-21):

# V22 layout post-repair snapshot review

Review time: `2026-07-26T14:27:04Z`

Scope: visual legibility and state-discrimination review only. Images do not
replace deterministic geometry checks, strength analysis, mechanism
qualification, or native SolidWorks configuration readback.

## Reviewed images

- `snapshots/layout_staging_iso_20260726T142704Z.png`
- `snapshots/layout_staging_iso_opposite_20260726T142704Z.png`
- `snapshots/layout_staging_top_20260726T142704Z.png`
- `snapshots/layout_staging_front_20260726T142704Z.png`
- `snapshots/state_STOWED_iso_20260726T142704Z.png`
- `snapshots/state_L_FAIL_top_20260726T142704Z.png`
- `snapshots/state_R_FAIL_top_20260726T142704Z.png`
- `snapshots/arm_stow_repaired_iso_20260726T142704Z.png`
- `snapshots/solar_sweep_repaired_iso_20260726T142704Z.png`

## Findings

- The primary isolated staging view shows the top longitudinal B601 stow
  corridor, two arm-support bridges and bilateral deployed solar wings in one
  traceable coordinate frame.
- The gray block geometry in Q0 states is visibly a conservative accepted-URDF
  proxy. It is not a vendor-shell or HIFI B601 model.
- `STOWED` contains the solar and physical support layout but no invented B601
  geometry, consistent with `HIFI_REQUIRED_NOT_AVAILABLE`.
- `L_FAIL` and `R_FAIL` are visibly asymmetric and mirror one another; the two
  state entrypoints are not aliases of the symmetric scene.
- The repaired arm-stow image shows a centered longitudinal corridor, a
  forward main-saddle station, an aft wrist station, and side equipment
  reservations.
- The repaired sweep image shows both solar sides rooted at their cassette
  interfaces across the sampled deployment fan.
- Cage and witness geometry is intentionally prominent so reservations,
  conflicts and unavailable authority are visible rather than silently
  converted into physical hardware.

## Visual HOLDs

- The shallow cassette pocket and retained `8.35 mm` inboard primary section
  are visually plausible only; strength, stiffness and tolerance remain HOLD.
- Fixed cassette rails/backplanes are load-path intent witnesses. Their
  overlaps with primary members are not qualified joints.
- The legacy top star-tracker conflict remains represented by a non-physical
  witness; the side relocation is a reservation only.
- No visual result establishes continuous global platform clearance,
  PRE_CAPTURE/SERVICE clearance, release reliability, mass, BOM, or flight
  qualification.

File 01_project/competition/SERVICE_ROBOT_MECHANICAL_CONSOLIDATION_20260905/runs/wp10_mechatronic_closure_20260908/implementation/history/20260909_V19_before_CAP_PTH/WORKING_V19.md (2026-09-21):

# WP10 V19 当前工作件：C203端接板与线束

本轮局部名义几何检查已完成；整机设计仍未完成。最后封装发布保持V18，原873组件／99位号父本及37行责任表保留。

| 当前对象 | 实际结果 |
|---|---|
| 原生PCB | WIRE两孔改为PTH；DRC从12降为6，余4项孔距与2项阻焊桥，均属于两处CAP孔群 |
| 分层STEP | PCB及两根导线已重生成，绑定同版本源和实际完成回执 |
| 螺钉与剥线 | 4颗M3×8头下平面X=-5.54；剥线4.2/3.6mm；C203端突出1.59mm |
| 当前集成 | 三态各972行：965行不变、5行修改、新增2线 |
| 精确几何 | 三态各31组邻件检查通过；每态9处名义接触通过 |
| 源检查 | 表面38项／14反例；线束22项／10反例；铜连接20项／5反例 |
| 电热计算 | 384状态、4800行替代热账，10反例通过；真实纹波仍未知 |

[打开可视化工作件](WORKING_V19.html) · [局部装配STEP](mechanical/cap_harness_assembly.step) · [PCB STEP](mechanical/input_cap_pcb.step)

[正线STEP](mechanical/cap_harness_plus.step) · [回线STEP](mechanical/cap_harness_minus.step) · [972行清单](mechanical/CAP_HARNESS_INSTANCE_PLAN_V19.json)

[精确检查](results/CAP_HARNESS_EXACT_V19.json) · [原生DRC](results/CAP_TERMINAL_DRC_NATIVE_V19.json) · [当前工作状态](results/CAP_HARNESS_WORKING_STATUS_V19.json)

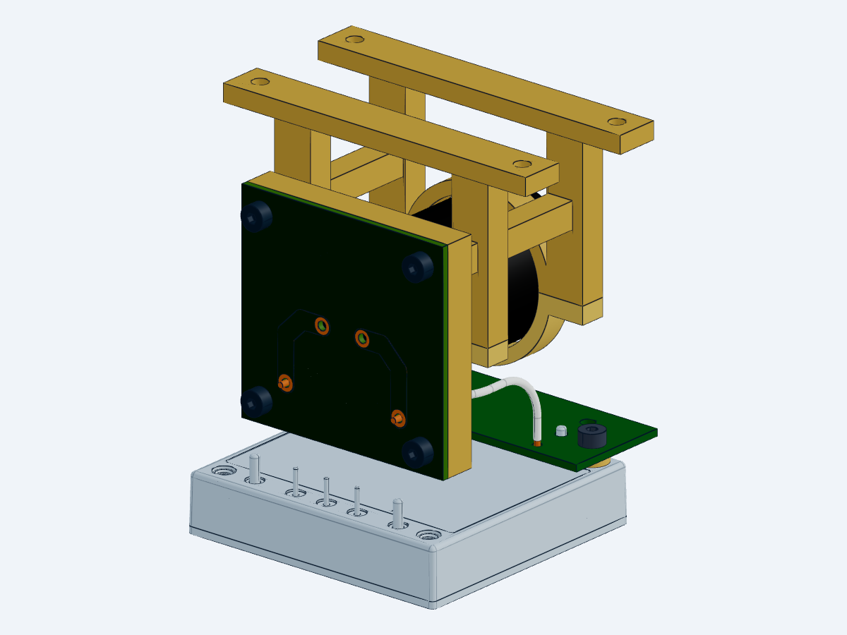
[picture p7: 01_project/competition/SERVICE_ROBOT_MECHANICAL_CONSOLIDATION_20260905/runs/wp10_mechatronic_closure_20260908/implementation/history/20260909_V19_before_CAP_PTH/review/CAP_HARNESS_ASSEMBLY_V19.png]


这是17个源实例的局部装配视图。原生检查跳过全局自交扫描；干涉证据限定本轮5改件和2导线、三种静态状态，未重复资格化其余965行。接触为名义几何，真实密封胶、板平整度、孔桶、焊点及预紧未资格化。

仍需完成：两处CAP孔的工艺一致性；线束卡箍／应变释放和焊接工具空间；CHB板局部表面；整机热路径、电池／PMM、推进同修订接口及任务能力。尚不能交付制造或据此宣称整星飞行设计完成。

首遍exact与assembly有8.813819秒排程重叠，已保留记录并完成串行重跑。后续本任务只经tools/run_cap19_serial.py入口启动原生作业；该入口保留2GiB启动、512MiB下限、自有子树1400MiB上限，不宣称能阻止所有外部直接启动入口。详见[排程修正记录](results/C203_NATIVE_SERIAL_CORRECTION_V19.json)。

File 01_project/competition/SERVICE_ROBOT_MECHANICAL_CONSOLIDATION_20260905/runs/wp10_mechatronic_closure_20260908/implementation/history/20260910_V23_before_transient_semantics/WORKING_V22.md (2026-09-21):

# WP10 V22：制动偏置 READY 接口已改件

2026-09-10 · 同一活动候选 · 机电整机闭环仍开放

内存清理后恢复工程检查。已关闭闲置 Windows 小组件，回收42个闲置工具及13个Claude进程的驻留页；Claude会话、Codex、系统服务保留。清理后连续可用内存为2.67/2.95/3.06GiB，超过2GiB启动门槛。原生任务采用串行内存保护。

本轮已通过KiCad MCP实际改动原生源：U303改为MAX5048CAUT+T；增加U304 MAX16053AUT+T、200k/10k分压、接收端100k下拉及延时/旁路电容，共新增6位号。LT3013 PG只作独立诊断，READY由偏置电压监测产生。绝对过压和独立STOP热故障连接保留。

|验证|本轮结果|范围|
|---|---|---|
|原生层级/网表|13页、207符号、521项通过|原99位号保留；原引脚仅U303.6改网|
|ERC|0错误、0警告；原4项忽略不变|首次误连/库路径问题已修复，失败记录保留|
|制动接口计算|124项通过|含5个数值反例；静态条件转用明列|
|启动与完整故障网|50项＋8项通过|同当前XML重新计算；不替代硬件试验|
|READY释放阈值|10.220577–10.782587V|名义10.5V，电阻/输入电流敏感性|
|READY高/低电平|≥10.367559V / ≤0.4V|输入负载条件转用；接收阈值2.0/0.8V|

[查看完整原生电气图纸，第13页为新增接口](ecad/wp10_system_v22.pdf) · [新增/变更器件表](ecad/BRAKE_ENABLE_BOM_DELTA_V22.csv) · [机器记录](results/WORKING_STATUS_V22.json)

实际原生PDF第13页

C302改为22µF名义、要求有效≥10µF；C305改为2.2µF名义、要求有效≥1µF。有效电容、物料、偏压、温度及布局资格仍待核验。C307选定KEMET C0603C102J5GACTU。新增监测约8.246mW为32V声明场景下的敏感性账，计入原有未验证1W制动偏置预留；机械臂360W未降低。

首次连续冷启动的0.5ms禁止期与TLV6700的450µs有效等待分别绑定原厂条款。延时电容参数给出2.999–5.528ms敏感性范围，不能当作保证最大延时；暖启动残压、实际回生轨迹、驱动器热关断、总线寄生与电容仍开放。

机械模型保留V21每状态974实例；新增电气器件尚未布板或加入CAD。V18封存页和原37行表保持原样，旧XML绑定证据不冒充V22整机验收。下一项优先工作为主保护三类故障过程和SOA配合，并继续完成制动驱动/PCB与热路径验证。

依据：[MAX5048C Rev1](https://www.analog.com/media/en/technical-documentation/data-sheets/MAX5048C.pdf)、[MAX16053 Rev7](https://www.analog.com/media/en/technical-documentation/data-sheets/MAX16052-MAX16053.pdf)、[KEMET电容规格](https://search.kemet.com/component-documentation/download/specsheet/C0603C102J5GACTU)。ADI原厂正文已在线核阅，本地PDF下载超时，未编造归档哈希。

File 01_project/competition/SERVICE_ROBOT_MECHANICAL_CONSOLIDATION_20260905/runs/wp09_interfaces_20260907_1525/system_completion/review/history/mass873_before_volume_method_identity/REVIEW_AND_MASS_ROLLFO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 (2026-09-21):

# 873 实例增量的独立审查与质量结转

本次独立审查完成 **943/943** 项来源、算术和连续区间检查；质量结转完成 **1081/1081** 项身份、源哈希及分账检查。审查没有调用 CAD、OCC、COM，也没有改写父本 705 质量账、冻结装配或科学 Gate。

[独立机器审查](<F:/China Graduate Future Flight Vehicle Innovation Competition/01_project/competition/SERVICE_ROBOT_MECHANICAL_CONSOLIDATION_20260905/runs/wp09_interfaces_20260907_1525/system_completion/results/INDEPENDENT_DELTA_REVIEW.json>)、[873 逐实例质量账](<F:/China Graduate Future Flight Vehicle Innovation Competition/01_project/competition/SERVICE_ROBOT_MECHANICAL_CONSOLIDATION_20260905/runs/wp09_interfaces_20260907_1525/system_completion/review/MASS_ASSIGNMENT_873.json>)、[逐实例 CSV](<F:/China Graduate Future Flight Vehicle Innovation Competition/01_project/competition/SERVICE_ROBOT_MECHANICAL_CONSOLIDATION_20260905/runs/wp09_interfaces_20260907_1525/system_completion/review/MASS_ASSIGNMENT_873.csv>)、[43 组汇总 CSV](<F:/China Graduate Future Flight Vehicle Innovation Competition/01_project/competition/SERVICE_ROBOT_MECHANICAL_CONSOLIDATION_20260905/runs/wp09_interfaces_20260907_1525/system_completion/review/MASS_OWNER_SUMMARY_873.csv>) 可直接复核。它们对应实际 STEP 增量和三态装配输入计划；原生装配的成功集成、冷读与图像审查以 CAD writer 的另行回执为准。

## 新发现和处置

仅发现一项新的来源元数据错误：R01 选型文件及生成器将 ISO 7092 垫圈资料写为 Rev0.1300、2025-10-10，已锁本地原厂 PDF 第 1 页实际为 **Rev0.1314、2026-08-03**。PDF SHA256 和几何/料号均一致，错误没有改变模型尺寸。已发布[版本勘误](<F:/China Graduate Future Flight Vehicle Innovation Competition/01_project/competition/SERVICE_ROBOT_MECHANICAL_CONSOLIDATION_20260905/runs/wp09_interfaces_20260907_1525/system_completion/review/SOURCE_REVISION_ERRATUM.json>)；为保留正在执行的 CAD 合同哈希，未修改原输入。后续主交付采用该勘误。

[原厂垫圈资料](https://marketplacemedia.witglobal.net/source/marketplace/stmedia/wuerth/documents/documents/std.lang.all/29208728.pdf) 支持 M3、内径 3.2、外径 6、厚 0.5 mm 和料号 515005013；当前网页缓存版本可能与本地锁定版不同，因此以 SHA 绑定的本地文件作为本次复现版本。另已逐页检查本地 Würth 螺钉/螺母 PDF：00843 10/12 为 ISO 4762 8.8 级螺钉，0324903 为 ISO 4032 10 级螺母，名义 AF5.5、高2.4 mm。

## 有限范围内已核实的设计

- R01 四种规格合计 128 个实例：M3×10/12 各 16，垫圈 64，螺母 32。2.52 mm AF 六角孔是明示的名义代理，2.5 mm AF 驱动工具的外接圆直径为 2.886751 mm；不能继承旧 Ø2.5 mm 圆柱工具的路径结论。每侧 0.01 mm 平面间隙只针对理想对正六角代理，不是工具、圆角、磨损或安装公差的保证。
- R01 原 128 件均采用烘焙整星 S 坐标与单位装配变换。新几何使用 128 个源坐标 STEP 替换；4 个 canonical 参考实体不计成额外装配件，也不加入质量。
- 原厂 CIC 的 40.15×80.15 mm 对应玻璃外形。成形互连片可能伸出，现有 84 层采用 `GLASS_FOOTPRINT_CIC_LAYER_PROXY`，完整包络仍未知。[原厂 General Information 第 7 页](https://www.azurspace.com/media/uploads/file_links/file/bdb_00010890-01-00_generalinformationazur.pdf) 对应 81442 的图号为 ZP0004289，完整 STEP 需索取。
- 独立按串联机构公式重算 776 个已认证区间，在每个区间重新检查全部 15 对板包络、分离轴与旋转位移上界。最小间隙下界 **0.3006434925831589 mm**，与原回执最大差 8.88×10⁻¹⁶ mm。4.5 mm 间距下的折叠厚度合同净缝为 0.82 mm。
- 连续证明只覆盖指定四段路径中的六块矩形板及最大面层；叉耳、销轴、机械臂、星体、焊片、布线、柔性、热变形和任意其他动作路径均不在证明内。不能写成“整机连续无碰撞”。

## 质量结转

873 个实例在三个状态中是同一套硬件，质量只计算一套。责任归属 873/873，共 43 组；物理或代表硬件为 872 个，另 1 个为纯预留空间。306 个有材料模型，94 个由整模块厂商参考值覆盖，合计 400/872；**472 个数值未闭合，涉及 30 组**。责任覆盖与数值覆盖分开报告。

| 项目 | 本次结转 |
|---|---:|
| 父本 705 已绑定材料模型小计 | 7.820206000189 kg |
| R01 128 个新代理的钢材模型 | +0.051978452357 kg |
| 8 个太阳翼边框新旧体积对应质量差 | +0.000118914850 kg |
| 当前材料模型部分小计 | **7.872303367396 kg** |
| B601 整臂厂家名义参考，独立列示 | 4.5 kg，整臂一次 |
| 84 个整 CIC 平均重量参考，独立列示 | 0.3024 kg，84×3.6 g |
| 84 层外部安装胶体积 | 27031.389 mm³ |
| 84 层外部安装胶质量 | 未知，密度/材料未选 |

R01 原705账中的质量是 null。因此不能只加“新旧几何差”0.000195382813 kg；正确做法是先绑定原几何钢材模型 0.051783069543 kg，再加该差，等价于直接加入新几何的 0.051978452357 kg，且仅一次。边框旧质量已存在，必须作替换差量。CIC 3.6 g 对应厂商整体平均重量参考，不是玻璃代理密度法质量，也不是实测单件值；其内部盖玻璃、原厂胶层、旁路二极管与原厂互连片不重复相加。外部板上安装胶是独立新增的正体积、未知质量。

原六片叶板各 0.18 kg 的历史预算是否包含 CIC 尚未绑定；它只留在非加和历史栏中。未将设备预算、材料估算和厂家名义数相加形成“整星总质量”。整星总质量、质心、惯量、实测质量及严格实物质量下界均保持 null。

## 保留的工程边界

标准料号选择和实体有效性不能替代真实螺纹、预紧/锁紧、圆角承压、扭矩、强度、完整工具通路和制造公差验证。板材铺层、嵌件、胶种、CIC 成形焊片及其串接线尚未形成完整接口。质量账仅覆盖当前装配计划中的实例；后续真实推进模块、高功率供电/充电、停机驱动、再生吸收器和阻断/布线等硬件若纳入整机，需要正式新增或替换实例及对应质量，不能以当前 873 数量宣称硬件齐套。

复现脚本为[独立区间审查](<F:/China Graduate Future Flight Vehicle Innovation Competition/01_project/competition/SERVICE_ROBOT_MECHANICAL_CONSOLIDATION_20260905/runs/wp09_interfaces_20260907_1525/system_completion/review/independent_review.py>)和[质量结转](<F:/China Graduate Future Flight Vehicle Innovation Competition/01_project/competition/SERVICE_ROBOT_MECHANICAL_CONSOLIDATION_20260905/runs/wp09_interfaces_20260907_1525/system_completion/review/mass_rollforward_873.py>)。全机详细机电设计完成、制造放行和物理验证信用均未授予。

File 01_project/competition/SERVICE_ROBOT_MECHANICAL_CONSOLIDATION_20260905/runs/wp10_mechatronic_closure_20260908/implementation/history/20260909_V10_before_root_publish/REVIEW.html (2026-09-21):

WP10 · 同一活动候选 · V10 四站主干支撑

# 四站主干线支撑及安装实体已集成

38实例/38实体原生SolidWorks已冷读；C09 CHB跨内核体积比较仍OPEN（1.16178e-6超过原1e-6判据），源STEP干涉结论未授予原生C09。894为三态候选源表。整机机电与热余量仍开放，没有制造、通电或飞行放行。

## 当前四站主干支撑与131件局部装配

三态各129对近邻和54处必需接触通过。931是完整源表数量，当前整星原生装配、机电详细设计仍未闭环。

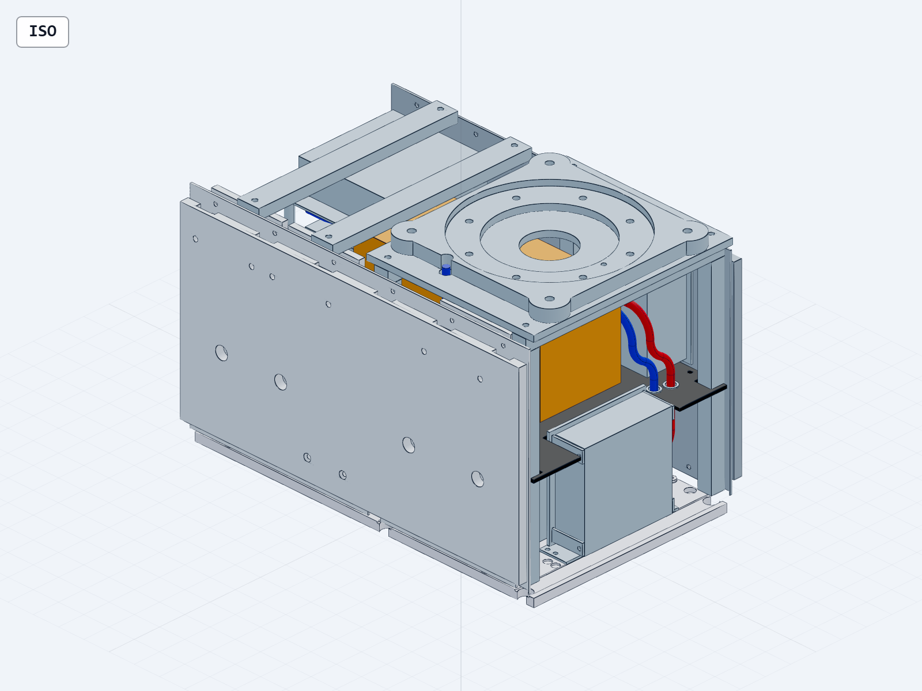
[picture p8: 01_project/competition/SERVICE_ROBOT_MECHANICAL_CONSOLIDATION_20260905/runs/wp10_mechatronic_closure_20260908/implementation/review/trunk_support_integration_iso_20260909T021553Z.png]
当前131件局部装配
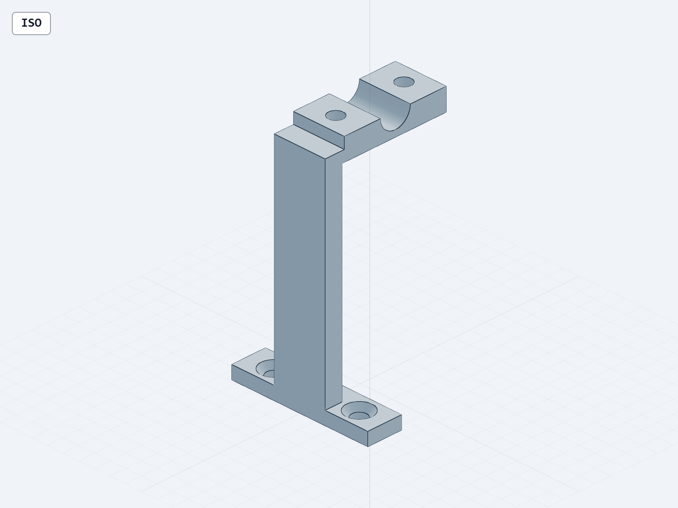
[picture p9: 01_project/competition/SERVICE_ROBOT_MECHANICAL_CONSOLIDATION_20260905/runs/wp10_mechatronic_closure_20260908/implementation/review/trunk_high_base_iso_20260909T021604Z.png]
高位支座与底脚实际实体
 

四夹具/四支撑ID已替换，增加8片衬套和30件紧固件，三块板源同步改孔/避让。4段释放支路与原入口反例仍保留；材料、防松、夹持力及全机验证未完成。

## 当前85件推进布线与电池舱局部装配

三态完整源表各893实例，仍保留12件未解决线束对象。85件是本轮局部STEP，当前整星原生SolidWorks和整机闭环未完成。

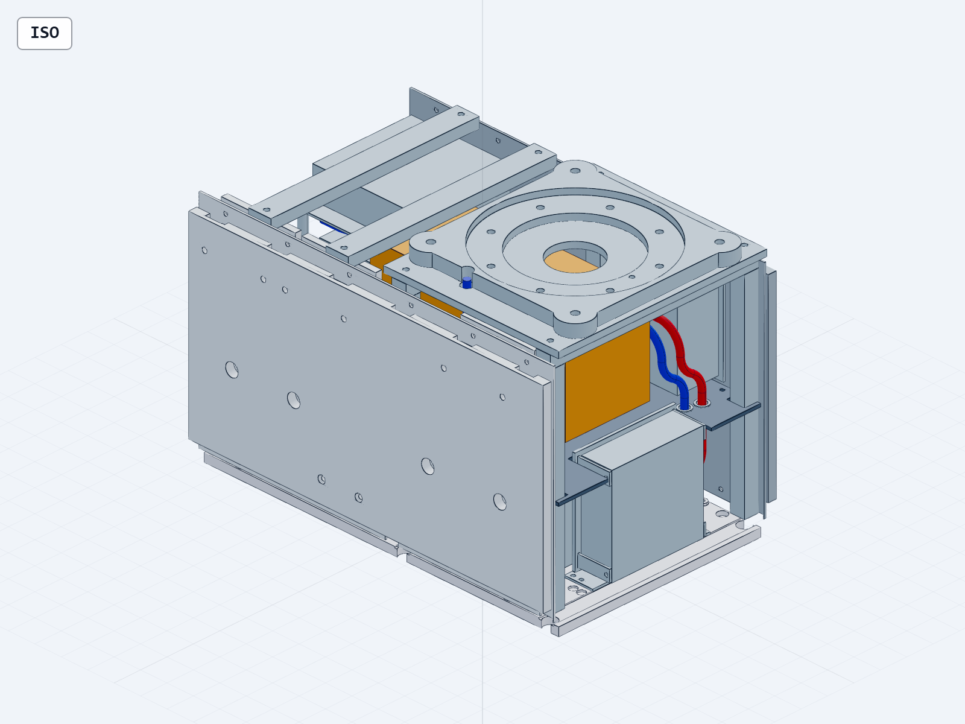
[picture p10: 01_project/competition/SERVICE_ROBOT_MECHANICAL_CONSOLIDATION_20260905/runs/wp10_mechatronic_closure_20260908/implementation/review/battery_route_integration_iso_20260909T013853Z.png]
当前85件推进线束和支撑修改
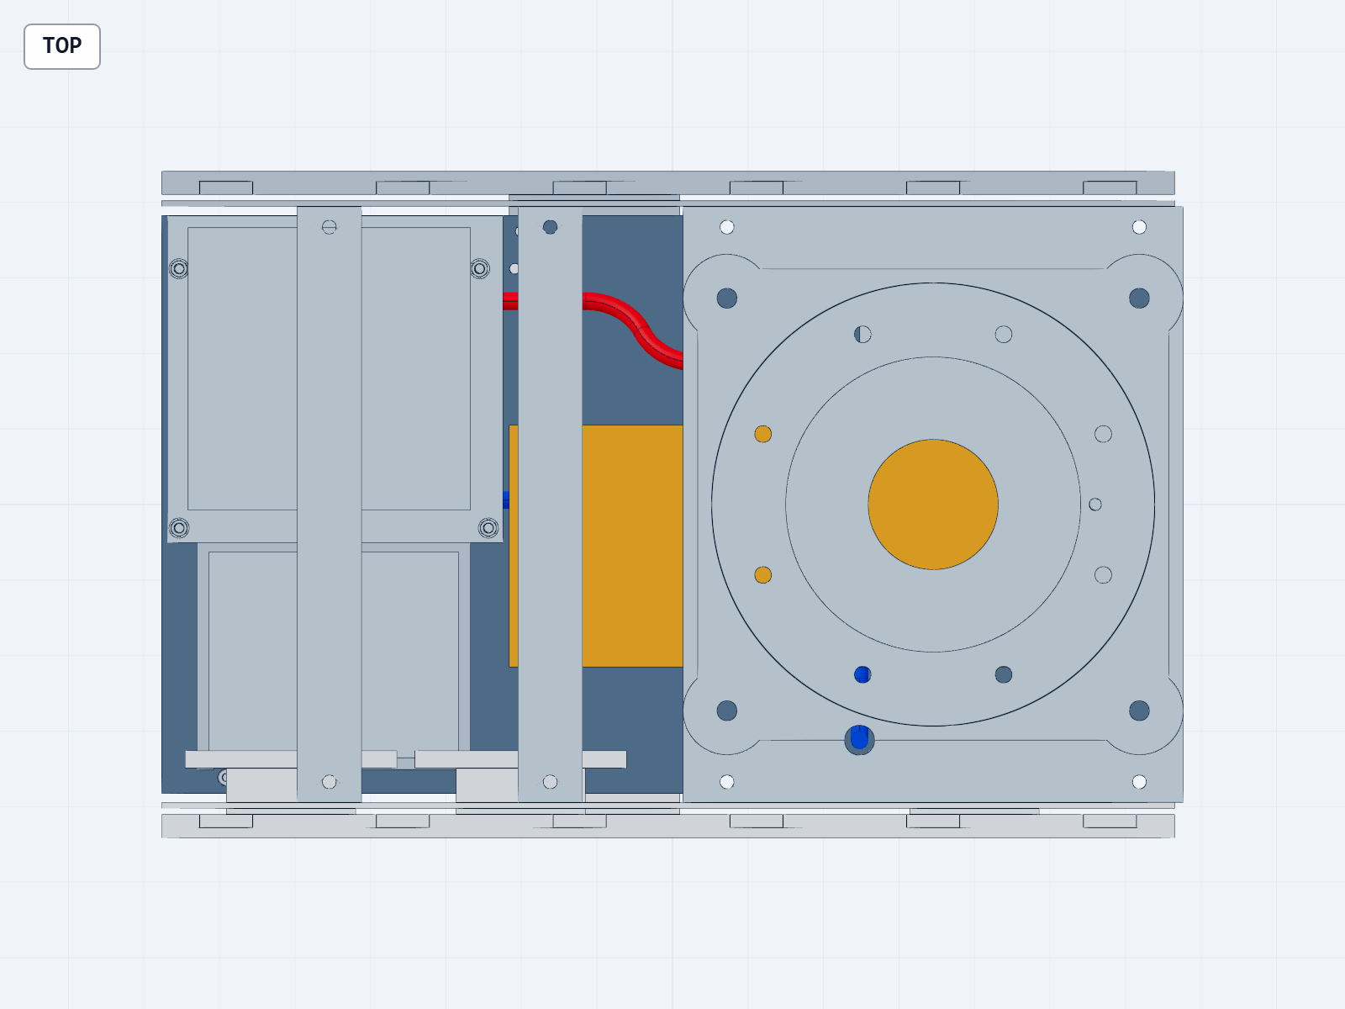
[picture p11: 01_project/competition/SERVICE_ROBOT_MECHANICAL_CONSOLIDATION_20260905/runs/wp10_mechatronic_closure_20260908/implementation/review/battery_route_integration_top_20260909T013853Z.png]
当前推进布局顶视图
 

17实例更新，三态各66对检查未发现穿透；两线最小间隙3.123238mm。DATA起点为未绑定的功能交接位置，夹具护套与夹持力未完成。释放入口及旧线路穿透保留，整体线束仍OPEN。

## 新增55件电池舱局部装配

电池采用厂家最大外包络，设备保持、27件线路夹具和2条释放支路仍需完善。本STEP未替代894整舱，未生成新的原生SolidWorks装配。

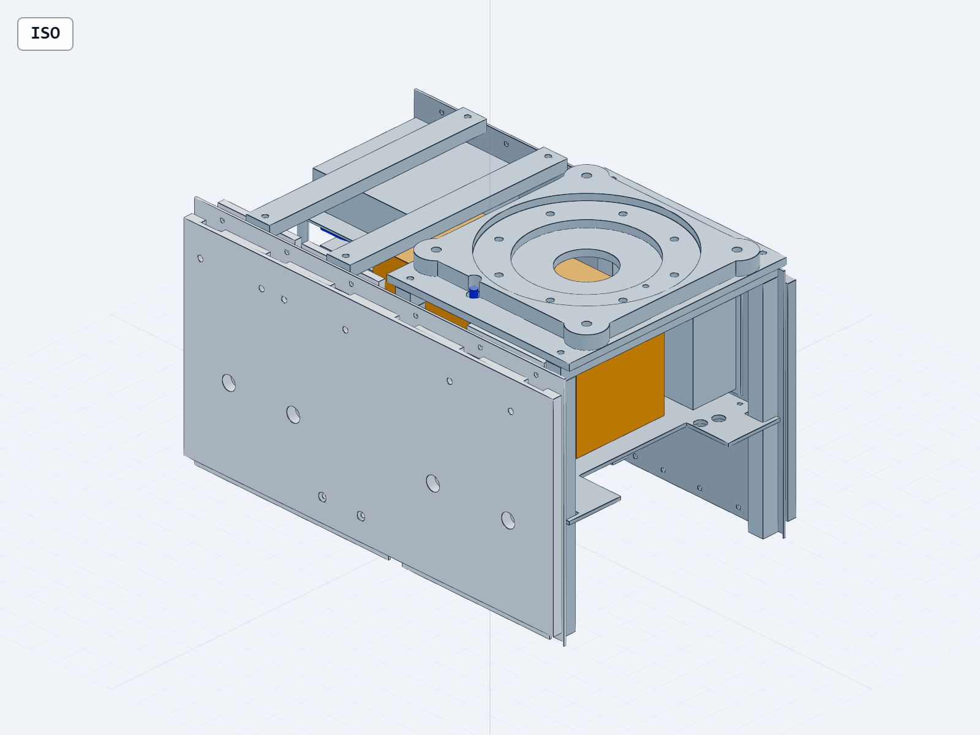
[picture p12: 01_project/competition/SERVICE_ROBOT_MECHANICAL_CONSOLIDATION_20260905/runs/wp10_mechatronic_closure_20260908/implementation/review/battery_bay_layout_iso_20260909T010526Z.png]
55件局部装配：电池外包络、迁移设备和主线通道
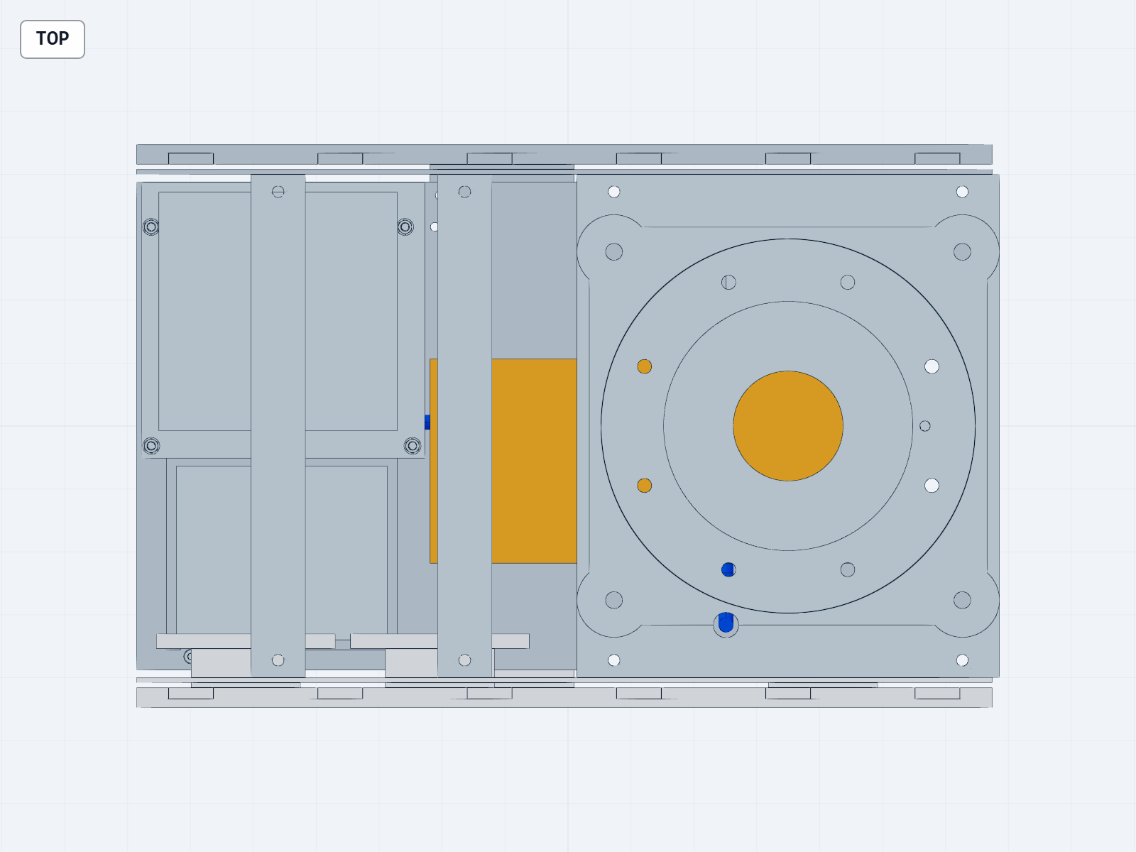
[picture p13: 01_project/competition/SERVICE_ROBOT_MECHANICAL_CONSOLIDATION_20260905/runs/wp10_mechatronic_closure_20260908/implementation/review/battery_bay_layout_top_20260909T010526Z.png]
电池舱局部顶视图
 

主线对电池间隙4.107556mm；桥板Ø10通孔与M3RB R5开边槽已清除原立段干涉。两条释放支路原105mm重合与各456.336140mm³安装板穿透仍OPEN。孔边强度、护套、夹具和端接尚未验收。

## 查看本轮实际装配

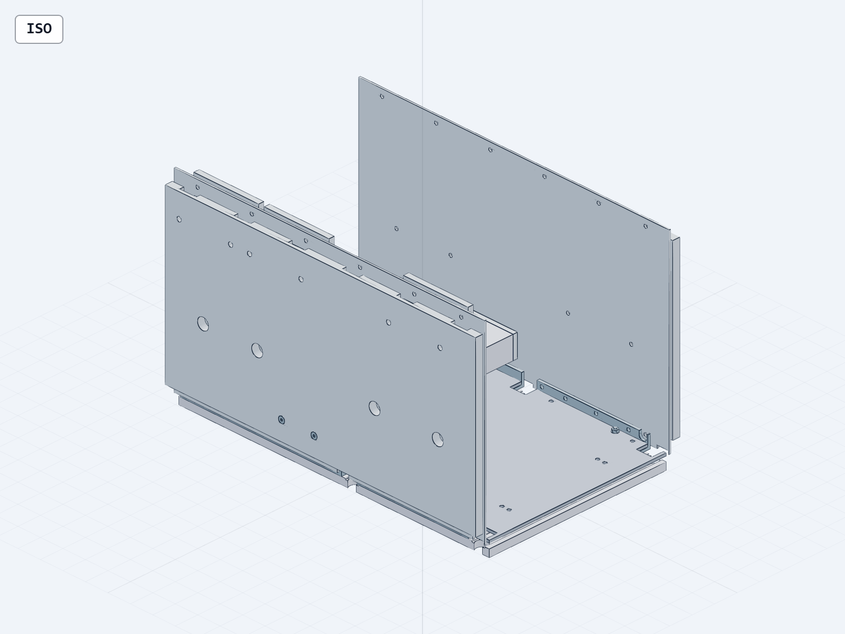
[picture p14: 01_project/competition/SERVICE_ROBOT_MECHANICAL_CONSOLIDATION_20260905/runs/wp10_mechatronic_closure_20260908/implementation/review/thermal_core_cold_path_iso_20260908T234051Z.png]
当前38实例导热核心


## 顶部导热路径

中央为CHB模块，两侧一体导热臂伸向壁座。薄TIM接触和隐藏区域以STEP接触检查为证据。

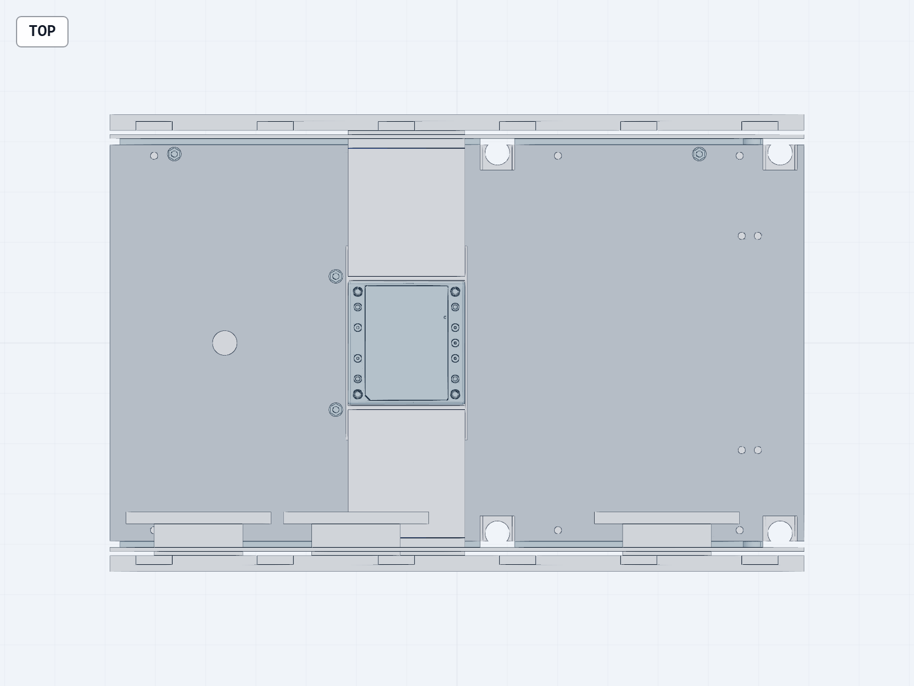
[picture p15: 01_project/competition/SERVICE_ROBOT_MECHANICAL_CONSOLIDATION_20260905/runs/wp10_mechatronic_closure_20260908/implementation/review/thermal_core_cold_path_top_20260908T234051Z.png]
当前导热核心顶视图


## 当前整舱改件

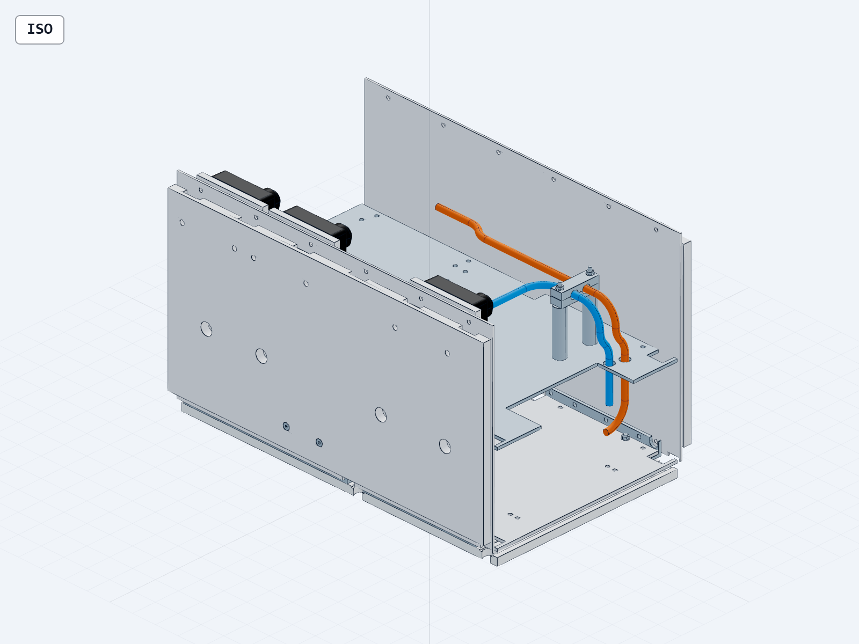
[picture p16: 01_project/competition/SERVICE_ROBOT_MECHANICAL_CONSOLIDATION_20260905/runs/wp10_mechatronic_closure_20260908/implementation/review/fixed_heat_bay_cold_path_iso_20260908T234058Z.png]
当前整舱改件


## 热计算及未闭环项

真实底板与双冷指已安装。模型纳入局部遮挡、反向热流和各接口热阻；其它模块、接触/涂层误差及真实轨道热环境仍需收束。数值检查通过不代表整星热通过。

## 同一候选电气与全部源包

## CHB 原生体积补充核查

显式低、中、高精度计算返回相同体积，最高精度比较仍未通过；原文件没有改动。

## 电池安装的下一处实际约束

RRC3570-4 D最大外形189.5×85.5×82.2mm，本轮已形成55件局部迁移与主线通道验证装配；电池托架及完整布置仍未完成。旧电池功能保留，厂家插座定位和保持区尺寸仍未绑定。

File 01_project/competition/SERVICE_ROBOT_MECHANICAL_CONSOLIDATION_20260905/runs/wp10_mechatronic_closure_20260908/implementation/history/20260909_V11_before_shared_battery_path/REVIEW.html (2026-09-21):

WP10 · 同一活动候选 · V11 桥板线束衬套

# 桥板过孔衬套与保持实体已集成

38实例/38实体原生SolidWorks已冷读；C09 CHB跨内核体积比较仍OPEN（1.16178e-6超过原1e-6判据），源STEP干涉结论未授予原生C09。894为三态候选源表。整机机电与热余量仍开放，没有制造、通电或飞行放行。

## 当前：桥板衬套与侧向保持件

三态各18对近邻、6处必需接触及两半轴向挡止通过。936是完整源表数量，整机机电设计仍开放。

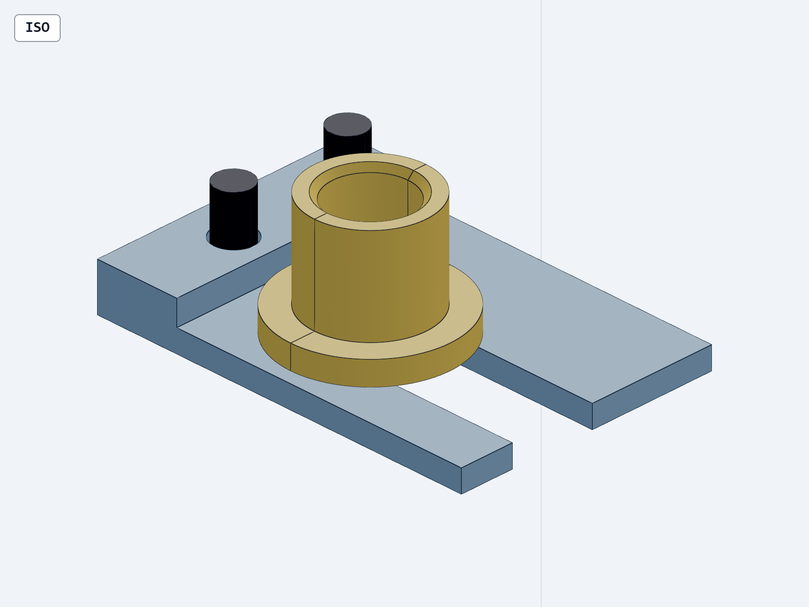
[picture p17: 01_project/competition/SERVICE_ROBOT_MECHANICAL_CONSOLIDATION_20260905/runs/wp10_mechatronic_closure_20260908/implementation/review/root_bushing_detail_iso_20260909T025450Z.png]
5件衬套组件，桥板未显示
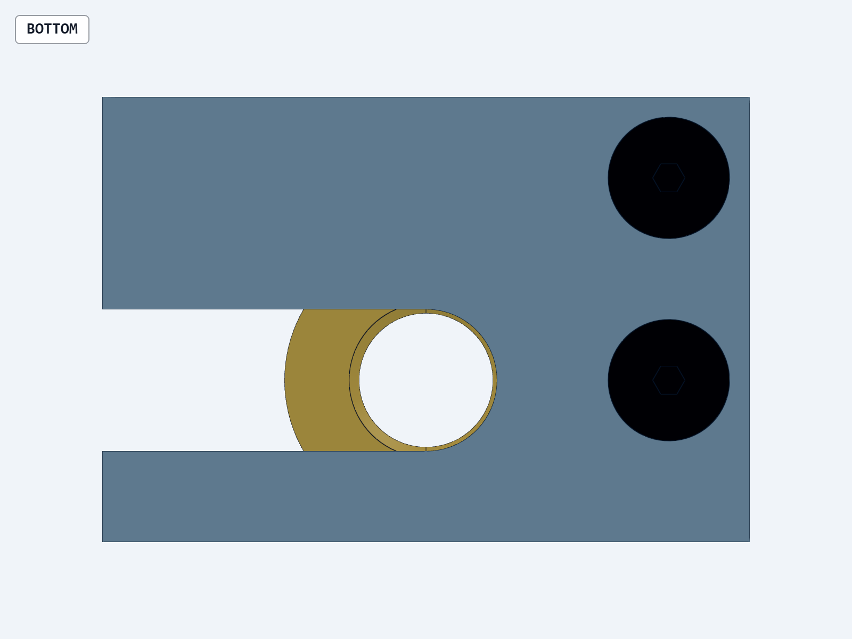
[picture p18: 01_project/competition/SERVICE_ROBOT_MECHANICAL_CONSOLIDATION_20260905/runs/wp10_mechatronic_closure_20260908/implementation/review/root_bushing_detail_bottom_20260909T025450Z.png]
压板底部双固定点
 

工具通道反例已改件修复。只保护桥板和M3RB下部2mm；上部边槽、应变释放及释放入口10°干涉保留。螺纹、材料、公差、强度和全机热验证未完成。

## 当前四站主干支撑与131件局部装配

三态各129对近邻和54处必需接触通过。931是完整源表数量，当前整星原生装配、机电详细设计仍未闭环。

当前131件局部装配 高位支座与底脚实际实体

四夹具/四支撑ID已替换，增加8片衬套和30件紧固件，三块板源同步改孔/避让。4段释放支路与原入口反例仍保留；材料、防松、夹持力及全机验证未完成。

## 当前85件推进布线与电池舱局部装配

三态完整源表各893实例，仍保留12件未解决线束对象。85件是本轮局部STEP，当前整星原生SolidWorks和整机闭环未完成。

当前85件推进线束和支撑修改 当前推进布局顶视图

17实例更新，三态各66对检查未发现穿透；两线最小间隙3.123238mm。DATA起点为未绑定的功能交接位置，夹具护套与夹持力未完成。释放入口及旧线路穿透保留，整体线束仍OPEN。

## 新增55件电池舱局部装配

电池采用厂家最大外包络，设备保持、27件线路夹具和2条释放支路仍需完善。本STEP未替代894整舱，未生成新的原生SolidWorks装配。

55件局部装配：电池外包络、迁移设备和主线通道 电池舱局部顶视图

主线对电池间隙4.107556mm；桥板Ø10通孔与M3RB R5开边槽已清除原立段干涉。两条释放支路原105mm重合与各456.336140mm³安装板穿透仍OPEN。孔边强度、护套、夹具和端接尚未验收。

## 查看本轮实际装配

当前38实例导热核心

## 顶部导热路径

中央为CHB模块，两侧一体导热臂伸向壁座。薄TIM接触和隐藏区域以STEP接触检查为证据。

当前导热核心顶视图

## 当前整舱改件

当前整舱改件

## 热计算及未闭环项

真实底板与双冷指已安装。模型纳入局部遮挡、反向热流和各接口热阻；其它模块、接触/涂层误差及真实轨道热环境仍需收束。数值检查通过不代表整星热通过。

## 同一候选电气与全部源包

## CHB 原生体积补充核查

显式低、中、高精度计算返回相同体积，最高精度比较仍未通过；原文件没有改动。

## 电池安装的下一处实际约束

RRC3570-4 D最大外形189.5×85.5×82.2mm，本轮已形成55件局部迁移与主线通道验证装配；电池托架及完整布置仍未完成。旧电池功能保留，厂家插座定位和保持区尺寸仍未绑定。

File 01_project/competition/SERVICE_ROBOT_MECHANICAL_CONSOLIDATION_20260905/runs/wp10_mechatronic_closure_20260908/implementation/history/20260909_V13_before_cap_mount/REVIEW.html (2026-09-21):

同一活动候选 · V13 输入器件改件 · 2026-09-09

# 主保险、极性电容与实际电路已绑定

本轮改件完成；整机机电设计仍开放。器件筛查、网表一致与独立复算通过，未执行制造、接电或实物试验。

改动 | 当前结果
F201主保险 | 1025HC30-RTR / 30A / 72VDC；故障L/R、温度降额和清除协调未闭合
C203输入电容 | ELXG101VSN222MR50S / 2200µF / 100V；pad1正、pad2负；全温纹波/寿命与安装开放
原生电气 | 201位号 / 11页 / 435项连接检查；保留7项未驱动电源引脚ERC
电源与热账 | 192场景，36项电源检查、26项器件筛查；16组欠压保持反例继续保留

## 输入电容的实际封装

KiCad原生导出C203封装

两Ø2mm圆孔，孔距10mm。顶视图左侧矩形pad1为正，右侧圆形pad2为负。

最大本体Ø31×52mm，顶部泄压再留3mm，接脚向下最大4.5mm。焊盘3.5mm为项目候选。

这份封装尚未路由到PCB或计入936实例装配；保持、绝缘和短输入回路需要实体落实。

初始120Hz ESR上界0.113036Ω；寿命试验后的参数边界可至0.376787Ω，不能继承全寿命通过。

## 原生改件页

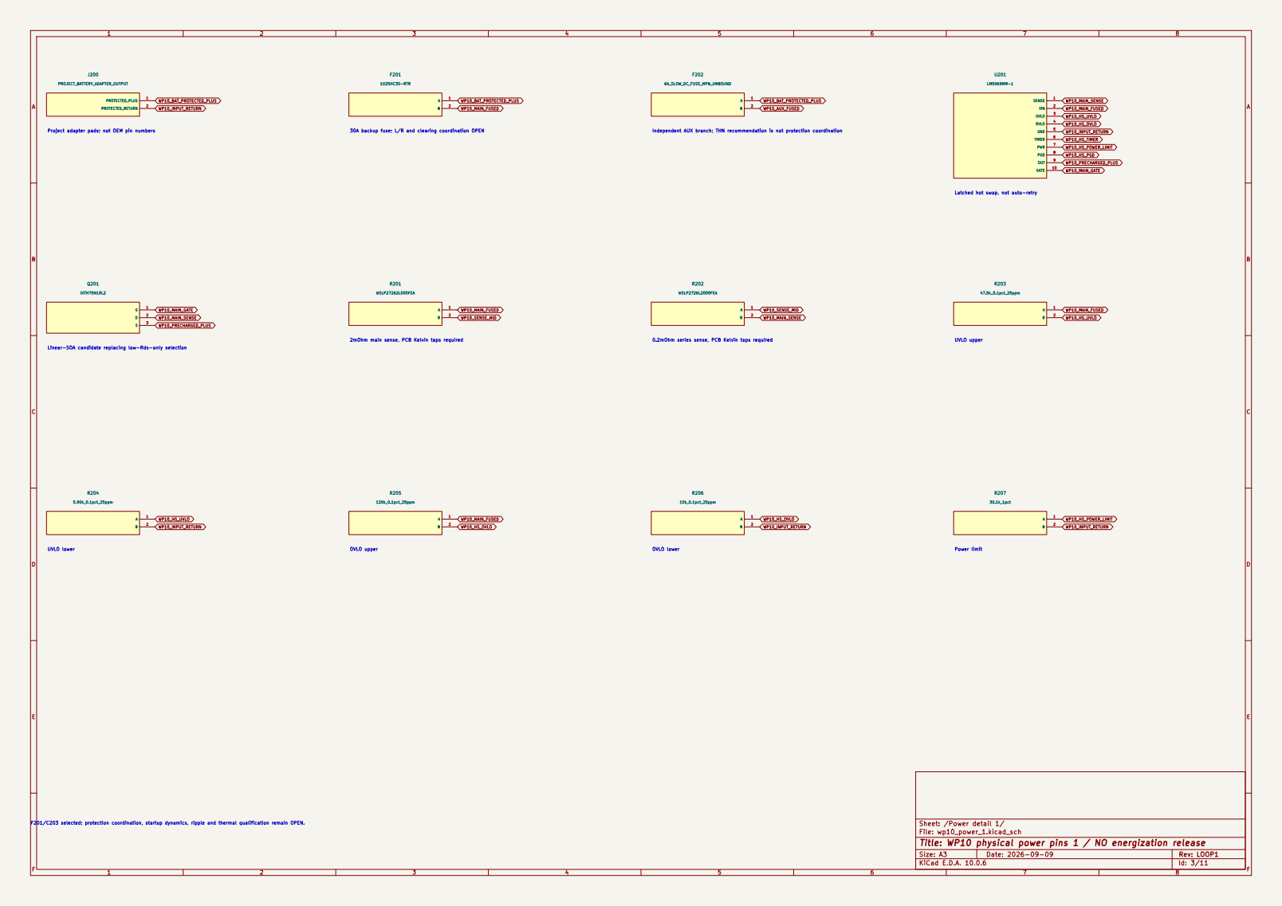
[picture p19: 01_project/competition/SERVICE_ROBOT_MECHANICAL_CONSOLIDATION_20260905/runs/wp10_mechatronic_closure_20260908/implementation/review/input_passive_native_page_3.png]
F201原生图纸
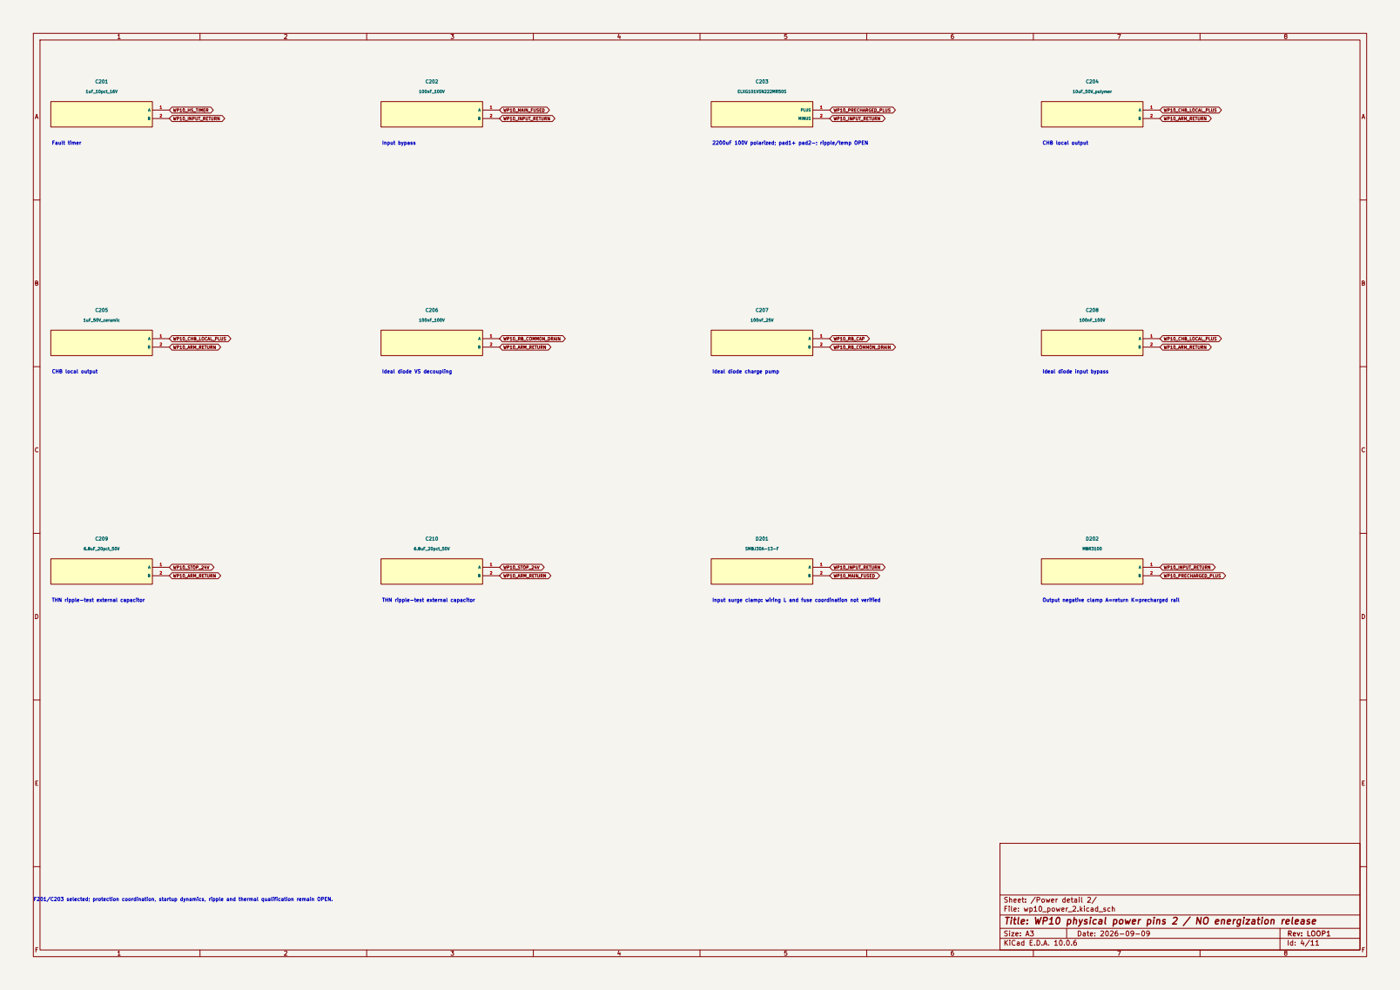
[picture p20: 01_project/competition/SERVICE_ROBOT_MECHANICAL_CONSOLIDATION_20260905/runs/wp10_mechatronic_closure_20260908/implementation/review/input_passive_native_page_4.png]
C203极性原生图纸
 

## 机械候选维持原版本

当前源表936实例、V11局部136件STEP未修改。既有38件原生SolidWorks热组件按旧验证范围保留；完整原生装配、承载/连续运动/全热验证尚未完成。

## 下一项实际设计

输入PCB与器件保持、保险和故障路径、C203纹波/寿命、SOA与停止动态。电池/PMM同修订安装接口、全热源和推进受控ICD继续逐项闭合。

内存清理回收闲置工具服务的可重载页，未结束应用；本轮原生构建均未触发内存保护。

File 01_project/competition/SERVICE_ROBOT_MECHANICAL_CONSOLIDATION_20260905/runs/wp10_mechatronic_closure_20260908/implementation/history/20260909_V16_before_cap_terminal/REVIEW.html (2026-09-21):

WP10 · V16 · 2026-09-09

# 电源声明已接入，ERC 错误已清零

新增 KiCad MCP 与 hardware-solution 审阅流程已用于实际源文件修改和原生检查。

0 / 0

ERC 错误 / 警告

201

实体位号保持

657

引脚连接与类型保持

16

回归测试通过

本轮完成 ERC 建模与检查器修正。电池厂家接口、保护配合、PCB/线束实物端接、停止回生热动态和推进 ICD 仍开放；整机未获制造、上电或飞行放行。原4项忽略规则保持，0/0仅针对已启用规则。

## 可追溯的供电声明

7个非物料标记均绑定真实设计路径和条件。输入与次级回流分开，U204 VS 保持共漏极，U301 保持接触器后的负载侧。原有10个电气子页的实体设计保持。

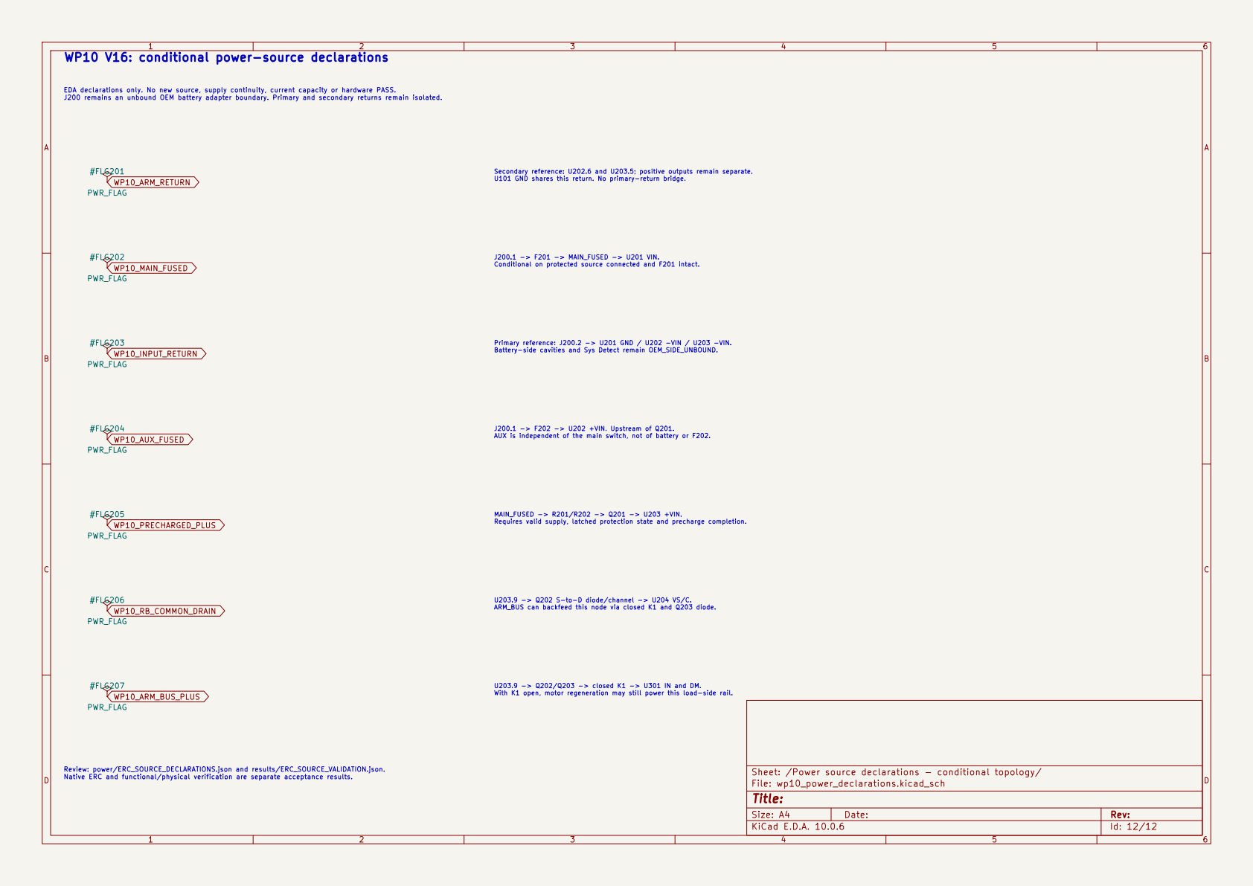
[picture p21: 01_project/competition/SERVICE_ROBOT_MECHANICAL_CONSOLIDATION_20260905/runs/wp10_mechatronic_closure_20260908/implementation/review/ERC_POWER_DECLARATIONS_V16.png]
原生KiCad导出的电源声明页


## 整机候选继续沿用

965组件机械候选与原873组件/99位号父本保留。C203接口对当前网表重新检查；本次没有新的实体几何修改。

下载现有C203/CHB局部装配STEP · 查看原有装配静态图

3D浏览服务因本机 build123d 字体读取异常未恢复；STEP文件与原生电气查看正常。

查看当前C203机电接口 · 查看三姿态局部检查 · 当前装配清单

下一步：B03 实际 PCB、导线、C203—CHB 端接和故障保护配合。

查看原37行责任项：13限定完成 / 19内部开放 / 4外部接口 / 1实物未执行

ID | 对象 | 状态 | 剩余设计
A01 | 705 三态固定姿态增量 | COMPLETE_SCOPED_SUBITEM | 此子项关闭；不代表承载连接或连续机构完成
A02 | R01 32 套连接的 128 标准件选型与材料模型 | COMPLETE_SCOPED_SUBITEM | 材料/标准选择子项完成；几何集成在 H02，连接承载在 A03
A03 | R01 与其余必需连接的有效啮合、防松、工具及承载 | INTERNAL_DESIGN_OPEN | 实际工具尚未选，夹层公差/不完整螺纹、预紧/防松和载荷验算未闭合；其余连接件不能继承 R01 选择
A04 | 六片太阳翼基板与边框实际固定 | INTERNAL_DESIGN_OPEN | 基板仍无孔、EDGE_INSERTS_TBD；板材/铺层、嵌件、紧固及粘接载荷路径未定
A05 | 电池、高功率支路、推进及状态传感器安装 | INTERNAL_DESIGN_OPEN | 新增电池及功率级安装未实现；推进受控安装面/端口未绑定；保持与状态检测的真实件未闭合
A06 | 责任件工程图、公差、处理及装配顺序 | INTERNAL_DESIGN_OPEN | 最终变化责任件同源工程图和全系统装配工艺未完成
B01 | 低功率 EPS 配置与负载限制合同 | COMPLETE_SCOPED_SUBITEM | 子项仅配置和限制定义，不证明全部能源链
B02 | P60/BPX 同修订线束、断路与充电保护 | EXTERNAL_INTERFACE_UNBOUND | 同配置针表/母板选件、保护回流/平衡/充电配套未绑定；仅按 NC 不等于整个组合兼容
B03 | 独立星上 360 W 机械臂完整受保护电源 | INTERNAL_DESIGN_OPEN | 电池充电/连接视向、全范围均流/BMS配合、瞬态、单故障、原理图/PCB/安装与热路径尚未完成
B04 | 84 CIC 的完整机电连接和温度电压 | EXTERNAL_INTERFACE_UNBOUND | 完整成形焊片外形、串接/阻断/绝缘/应变释放、胶材料及冷温 Voc 保证尚未关闭
B05 | 完整任务模式与轨道能源收支 | INTERNAL_DESIGN_OPEN | 示例轨道/姿态/日照/阴影及操作占空未绑定现任务；启动/峰值/制动/恢复全负载模型不完整
B06 | A3200 唯一正式供电支路 | INTERNAL_DESIGN_OPEN | 该范围不是所选 PDU 保证；启动/限流/热态接触电阻及 P1/FSI 实际互斥未闭合
C01 | GX11CAB 具体选择和正线切断拓扑 | COMPLETE_SCOPED_SUBITEM | 子项完成；不称全电隔离、不称辅助 NO 为镜像安全触点
C02 | 停止监督离线命令策略 | COMPLETE_SCOPED_SUBITEM | 仅命令策略；无 MCU 构建、实际驱动或安全时间证明
C03 | 独立停止链、线圈驱动/反馈/故障检测电路 | INTERNAL_DESIGN_OPEN | 纹波/启动/瞬态及15.7/13.5mV恢复裕度、Schmitt连续电压域阈值、棕断行为、MCU/母线健康、PCB热布局与全链100ms仍未闭合
C04 | 掉电可用回生能量去路与脉冲/平均热 | INTERNAL_DESIGN_OPEN | 真实组合体惯量/速度/重力项及电阻脉冲曲线、掉电吸收/过温处置、温升安装未闭合
C05 | 失扭矩承托及完整 GSE 防护 | INTERNAL_DESIGN_OPEN | 承托实体/传感器/额定载荷、AC/PE/应变释放、制动罩壳及 PCB 固定尚不完整
D01 | 推进公开资料锁版及必要条件排除 | COMPLETE_SCOPED_SUBITEM | 完成的是资料身份及条件排除；不构成实际推进能力
D02 | 具体推进模块的机械/电气/软件受控接口 | EXTERNAL_INTERFACE_UNBOUND | 总孔数/坐标/深度/保持载荷、实际喷口方向/命令映射/并发/推进器针表/CRC遥测与故障态仍未获得受控ICD
D03 | 推进实际任务与预算闭环 | INTERNAL_DESIGN_OPEN | 现任务矢量/平移许可/时间窗、最终 mass/COM 与真实 nozzle 未绑定；缺受约束分配和必要时域
D04 | 推进实际安装、维护与工作喷流 | INTERNAL_DESIGN_OPEN | 未给最终空置净空间、受控安装变换/保持载荷、工具和羽流路径
E01 | 现有系统 KiCad 与主 From–To 同源 | COMPLETE_SCOPED_SUBITEM | 保留2项抽象保护/开关后电源驱动ERC诊断，不加PWR_FLAG；ERC数量不代表功能覆盖
E02 | 独立 RS422 地面无源转接板 | COMPLETE_SCOPED_SUBITEM | 板级导体设计完成；罩壳、焊线卸载和成品工艺属于C05/E05，不是推进接口认证
E03 | MotorBridge 原始源与 DM 离线适配 | COMPLETE_SCOPED_SUBITEM | 未本机重编Rust；原生MIT编码/串口后端与硬件I/O未执行。ctypes布局仅匹配reprC声明，未在DLL内部探测布局
E04 | B601 DM 实际关节/端接及星上控制路径 | EXTERNAL_INTERFACE_UNBOUND | 公开参考不等于出货实机；方向/传动比/零位/机械限位/针位视向/固件与星上CAN后端仍未绑定
E05 | 全部必需线束三维路径/端接/裁线/保护 | INTERNAL_DESIGN_OPEN | 尚缺完整触点/工具配套、R≥120动态路由、夹紧载荷、弯曲/活动余量、连接器穿入与裁线长度
E06 | 必需状态检测、控制供电及真实系统原理图 | INTERNAL_DESIGN_OPEN | 供源动态与掉电证明、MCU电压域和实际健康观测、连接器/PCB及其他设备状态反馈未齐
F01 | 873 实例质量责任归属和 R01 子账 | COMPLETE_SCOPED_SUBITEM | 归属及数据入口完成；整B6014.5kg不可平均分配为各link，未知物性继续F02
F02 | 最终实例质量上下界、三态 COM/惯量与捕获组合 | INTERNAL_DESIGN_OPEN | B601逐link分布、设备包络/平均重量的真实惯性、全运动树/刚体分组及全星COM/I/推进剂状态仍未闭合
F03 | 星上导热/辐射及 GSE 对流热设计 | INTERNAL_DESIGN_OPEN | 电池、驱动、回生、电源、推进热路径/界面/工况/温升未实现完整计算
G01 | 六矩形面层太阳翼四段连续间隙 | COMPLETE_SCOPED_SUBITEM | 仅六块保守层包络、指定单关节四段；排除tab/框销/整星/臂/线束/柔性
G02 | 完整机构动作、机械臂释放/工作域、活动线束与维护 | INTERNAL_DESIGN_OPEN | 真实框销/锁定保持/整星/臂/tab/线束连续碰撞及装拆路径未覆盖；机械臂允许工作域未绑定
G03 | 当前结构载荷路径与分级强度/刚度/稳定性 | INTERNAL_DESIGN_OPEN | 当前板/支架/电池/推进/机械臂基座/保持连接的载荷、许用、公差与边界未统一验算
H01 | 705 三态可迁移原生包 | COMPLETE_SCOPED_SUBITEM | 此子项完成；搬移验证不等于在第二台机器实际测试，也不自动覆盖新增873候选
H02 | 太阳面层/铰链和R01联合原生增量 | COMPLETE_SCOPED_SUBITEM | 本轮增量交付子项关闭；全机电一致及未完成设计仍在H03和A-G
H03 | 全套机电 BOM/接口/制造数据一致与设计复现 | INTERNAL_DESIGN_OPEN | 停止PCB/安装件、全部真实线束/图纸/控制和推进接口及整机物性仍未齐；不能以子包完整性宣布全部完成
H04 | 原24项物理检验与后续到货/制造检查 | PHYSICAL_NOT_EXECUTED | 物理未执行独立记录；表中未绑定设计输入须先在A-G关闭，不能改名为到货检查清零

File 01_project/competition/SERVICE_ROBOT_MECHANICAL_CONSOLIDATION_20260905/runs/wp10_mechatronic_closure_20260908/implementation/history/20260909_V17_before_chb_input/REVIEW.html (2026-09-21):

WP10 · V17 · 2026-09-09 · 同一工程候选

# C203端接板已布铜，导线孔已集成

KiCad MCP、参数化 CAD 和只读复核已用于实际源文件修改及反例修复。

0 / 0

整机 ERC 错误 / 警告

12

C203 PCB DRC 开放项

20 + 5

铜检查 + 故障反例通过

37

当前局部装配实体

整机详细设计尚未完成。C203板的8项孔距、4项阻焊桥错误仍需加工/焊接处置；CHB实际端接、导线保持和保护配合继续开放。ERC 0/0仅覆盖启用规则，原4项忽略保持。

## 实际板图与孔位

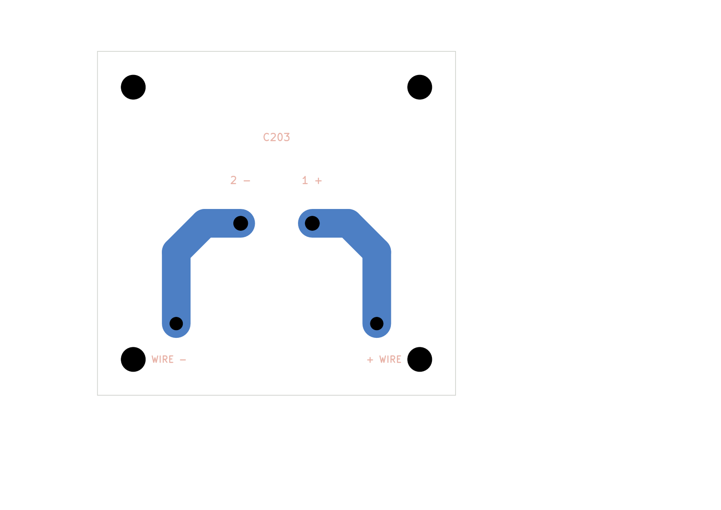
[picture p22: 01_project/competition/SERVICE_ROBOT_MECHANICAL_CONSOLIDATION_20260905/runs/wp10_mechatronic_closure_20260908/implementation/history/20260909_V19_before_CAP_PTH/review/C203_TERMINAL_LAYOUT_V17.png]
原生KiCad导出的C203背面铜图


50×48 mm板，背面70 μm铜、4 mm走线；4个物理电气端点、8个无金属化孔。

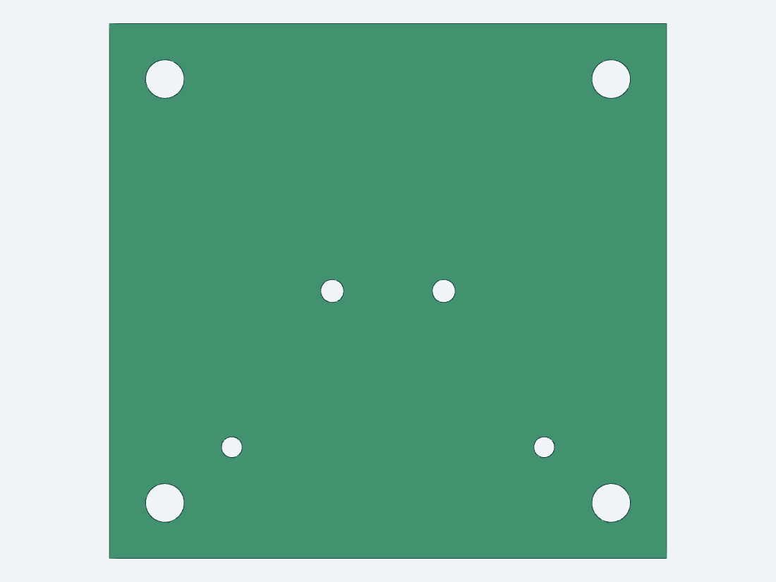
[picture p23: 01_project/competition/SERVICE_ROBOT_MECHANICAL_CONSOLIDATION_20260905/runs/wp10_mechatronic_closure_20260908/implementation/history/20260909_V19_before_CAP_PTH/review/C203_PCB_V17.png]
当前C203 PCB STEP实物包络，包含两个新增导线孔


机械STEP只表达1.6 mm成品包络。两个新导线孔Ø1.8 mm；铜和芯板材料未分别建模。

## 同版本局部装配

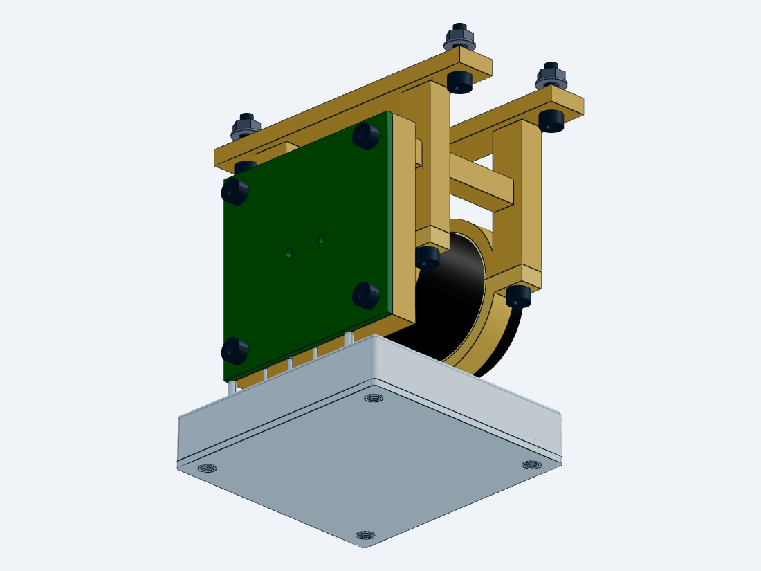
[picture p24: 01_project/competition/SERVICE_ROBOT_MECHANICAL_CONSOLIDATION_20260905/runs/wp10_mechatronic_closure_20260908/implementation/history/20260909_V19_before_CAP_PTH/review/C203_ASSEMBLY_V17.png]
当前37件C203和CHB局部装配，隐藏7个遮挡背景件后显示30件


为观察电容与CHB，查看图隐藏上/下设备板、外辐射板、电池及其适配板、推进分配块及其适配板，共7件。三姿态局部检查保留这些部件；未进行965组件整体或连续动作验收。

## 检查器已修复的反例

相同引脚号不再替代实际铜连通检查。移除走线、断开单段、桥接正负及零面积相切均被检出；封装内部铜图元已纳入检查。当前两网名义铜距6 mm，WIRE端铜包络窗口余量0.50 mm，均未取得公差或工艺资格。

## 下一责任件

CHB输入端接板、C203至CHB短配对导线及保持结构；同时补齐单面孔加工/焊接、低电感与保护配合。电池/PMM、停止回生热动态、同修订推进ICD继续按原闭环表推进。

原37行状态：13限定完成 /19内部开放 /4外部接口 /1实物未执行

ID | 对象 | 状态 | 剩余设计
A01 | 705 三态固定姿态增量 | COMPLETE_SCOPED_SUBITEM | 此子项关闭；不代表承载连接或连续机构完成
A02 | R01 32 套连接的 128 标准件选型与材料模型 | COMPLETE_SCOPED_SUBITEM | 材料/标准选择子项完成；几何集成在 H02，连接承载在 A03
A03 | R01 与其余必需连接的有效啮合、防松、工具及承载 | INTERNAL_DESIGN_OPEN | 实际工具尚未选，夹层公差/不完整螺纹、预紧/防松和载荷验算未闭合；其余连接件不能继承 R01 选择
A04 | 六片太阳翼基板与边框实际固定 | INTERNAL_DESIGN_OPEN | 基板仍无孔、EDGE_INSERTS_TBD；板材/铺层、嵌件、紧固及粘接载荷路径未定
A05 | 电池、高功率支路、推进及状态传感器安装 | INTERNAL_DESIGN_OPEN | 新增电池及功率级安装未实现；推进受控安装面/端口未绑定；保持与状态检测的真实件未闭合
A06 | 责任件工程图、公差、处理及装配顺序 | INTERNAL_DESIGN_OPEN | 最终变化责任件同源工程图和全系统装配工艺未完成
B01 | 低功率 EPS 配置与负载限制合同 | COMPLETE_SCOPED_SUBITEM | 子项仅配置和限制定义，不证明全部能源链
B02 | P60/BPX 同修订线束、断路与充电保护 | EXTERNAL_INTERFACE_UNBOUND | 同配置针表/母板选件、保护回流/平衡/充电配套未绑定；仅按 NC 不等于整个组合兼容
B03 | 独立星上 360 W 机械臂完整受保护电源 | INTERNAL_DESIGN_OPEN | 电池充电/连接视向、全范围均流/BMS配合、瞬态、单故障、原理图/PCB/安装与热路径尚未完成
B04 | 84 CIC 的完整机电连接和温度电压 | EXTERNAL_INTERFACE_UNBOUND | 完整成形焊片外形、串接/阻断/绝缘/应变释放、胶材料及冷温 Voc 保证尚未关闭
B05 | 完整任务模式与轨道能源收支 | INTERNAL_DESIGN_OPEN | 示例轨道/姿态/日照/阴影及操作占空未绑定现任务；启动/峰值/制动/恢复全负载模型不完整
B06 | A3200 唯一正式供电支路 | INTERNAL_DESIGN_OPEN | 该范围不是所选 PDU 保证；启动/限流/热态接触电阻及 P1/FSI 实际互斥未闭合
C01 | GX11CAB 具体选择和正线切断拓扑 | COMPLETE_SCOPED_SUBITEM | 子项完成；不称全电隔离、不称辅助 NO 为镜像安全触点
C02 | 停止监督离线命令策略 | COMPLETE_SCOPED_SUBITEM | 仅命令策略；无 MCU 构建、实际驱动或安全时间证明
C03 | 独立停止链、线圈驱动/反馈/故障检测电路 | INTERNAL_DESIGN_OPEN | 纹波/启动/瞬态及15.7/13.5mV恢复裕度、Schmitt连续电压域阈值、棕断行为、MCU/母线健康、PCB热布局与全链100ms仍未闭合
C04 | 掉电可用回生能量去路与脉冲/平均热 | INTERNAL_DESIGN_OPEN | 真实组合体惯量/速度/重力项及电阻脉冲曲线、掉电吸收/过温处置、温升安装未闭合
C05 | 失扭矩承托及完整 GSE 防护 | INTERNAL_DESIGN_OPEN | 承托实体/传感器/额定载荷、AC/PE/应变释放、制动罩壳及 PCB 固定尚不完整
D01 | 推进公开资料锁版及必要条件排除 | COMPLETE_SCOPED_SUBITEM | 完成的是资料身份及条件排除；不构成实际推进能力
D02 | 具体推进模块的机械/电气/软件受控接口 | EXTERNAL_INTERFACE_UNBOUND | 总孔数/坐标/深度/保持载荷、实际喷口方向/命令映射/并发/推进器针表/CRC遥测与故障态仍未获得受控ICD
D03 | 推进实际任务与预算闭环 | INTERNAL_DESIGN_OPEN | 现任务矢量/平移许可/时间窗、最终 mass/COM 与真实 nozzle 未绑定；缺受约束分配和必要时域
D04 | 推进实际安装、维护与工作喷流 | INTERNAL_DESIGN_OPEN | 未给最终空置净空间、受控安装变换/保持载荷、工具和羽流路径
E01 | 现有系统 KiCad 与主 From–To 同源 | COMPLETE_SCOPED_SUBITEM | 保留2项抽象保护/开关后电源驱动ERC诊断，不加PWR_FLAG；ERC数量不代表功能覆盖
E02 | 独立 RS422 地面无源转接板 | COMPLETE_SCOPED_SUBITEM | 板级导体设计完成；罩壳、焊线卸载和成品工艺属于C05/E05，不是推进接口认证
E03 | MotorBridge 原始源与 DM 离线适配 | COMPLETE_SCOPED_SUBITEM | 未本机重编Rust；原生MIT编码/串口后端与硬件I/O未执行。ctypes布局仅匹配reprC声明，未在DLL内部探测布局
E04 | B601 DM 实际关节/端接及星上控制路径 | EXTERNAL_INTERFACE_UNBOUND | 公开参考不等于出货实机；方向/传动比/零位/机械限位/针位视向/固件与星上CAN后端仍未绑定
E05 | 全部必需线束三维路径/端接/裁线/保护 | INTERNAL_DESIGN_OPEN | 尚缺完整触点/工具配套、R≥120动态路由、夹紧载荷、弯曲/活动余量、连接器穿入与裁线长度
E06 | 必需状态检测、控制供电及真实系统原理图 | INTERNAL_DESIGN_OPEN | 供源动态与掉电证明、MCU电压域和实际健康观测、连接器/PCB及其他设备状态反馈未齐
F01 | 873 实例质量责任归属和 R01 子账 | COMPLETE_SCOPED_SUBITEM | 归属及数据入口完成；整B6014.5kg不可平均分配为各link，未知物性继续F02
F02 | 最终实例质量上下界、三态 COM/惯量与捕获组合 | INTERNAL_DESIGN_OPEN | B601逐link分布、设备包络/平均重量的真实惯性、全运动树/刚体分组及全星COM/I/推进剂状态仍未闭合
F03 | 星上导热/辐射及 GSE 对流热设计 | INTERNAL_DESIGN_OPEN | 电池、驱动、回生、电源、推进热路径/界面/工况/温升未实现完整计算
G01 | 六矩形面层太阳翼四段连续间隙 | COMPLETE_SCOPED_SUBITEM | 仅六块保守层包络、指定单关节四段；排除tab/框销/整星/臂/线束/柔性
G02 | 完整机构动作、机械臂释放/工作域、活动线束与维护 | INTERNAL_DESIGN_OPEN | 真实框销/锁定保持/整星/臂/tab/线束连续碰撞及装拆路径未覆盖；机械臂允许工作域未绑定
G03 | 当前结构载荷路径与分级强度/刚度/稳定性 | INTERNAL_DESIGN_OPEN | 当前板/支架/电池/推进/机械臂基座/保持连接的载荷、许用、公差与边界未统一验算
H01 | 705 三态可迁移原生包 | COMPLETE_SCOPED_SUBITEM | 此子项完成；搬移验证不等于在第二台机器实际测试，也不自动覆盖新增873候选
H02 | 太阳面层/铰链和R01联合原生增量 | COMPLETE_SCOPED_SUBITEM | 本轮增量交付子项关闭；全机电一致及未完成设计仍在H03和A-G
H03 | 全套机电 BOM/接口/制造数据一致与设计复现 | INTERNAL_DESIGN_OPEN | 停止PCB/安装件、全部真实线束/图纸/控制和推进接口及整机物性仍未齐；不能以子包完整性宣布全部完成
H04 | 原24项物理检验与后续到货/制造检查 | PHYSICAL_NOT_EXECUTED | 物理未执行独立记录；表中未绑定设计输入须先在A-G关闭，不能改名为到货检查清零

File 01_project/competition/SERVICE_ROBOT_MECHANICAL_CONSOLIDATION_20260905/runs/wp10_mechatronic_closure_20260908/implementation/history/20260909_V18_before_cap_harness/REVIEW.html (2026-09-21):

WP10 · V18 · 同一工程候选 · 2026-09-09

# CHB输入端接板及固定结构已集成

主馈、电容支线与使能端已落实到原生PCB、具体孔位和装配实体。

0 / 0

新CHB板 DRC错误 / 警告

6 + 7

铜检查 / 故障反例通过

970

三态源清单；原965行保持

11

可查看的局部装配实例

整机详细设计尚未完成。实际C203导线、主馈和控制回线、应力释放及保护配合仍开放；原C203板的12项DRC未消除。新板0/0覆盖启用规则，原5项默认忽略保持。未制造、上电或飞行放行。

## 实际装配

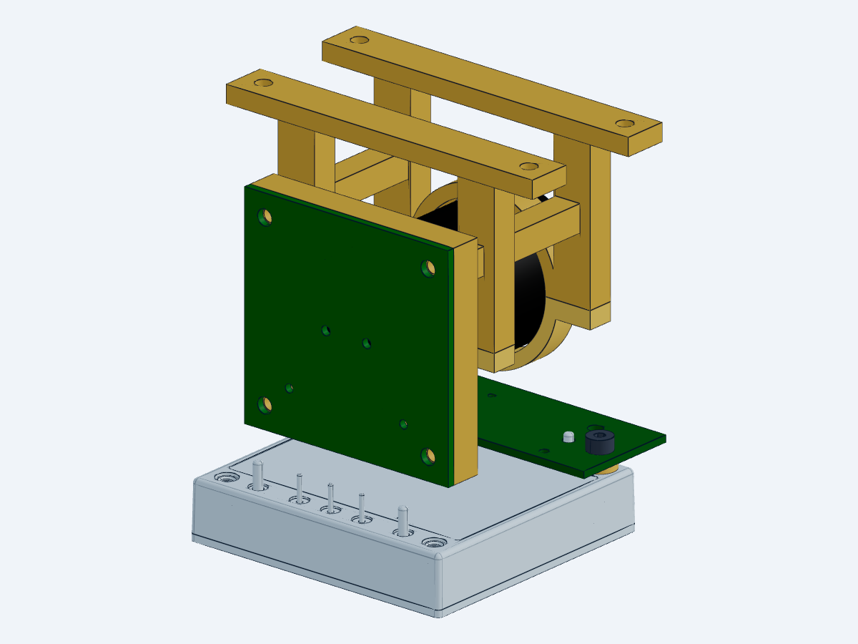
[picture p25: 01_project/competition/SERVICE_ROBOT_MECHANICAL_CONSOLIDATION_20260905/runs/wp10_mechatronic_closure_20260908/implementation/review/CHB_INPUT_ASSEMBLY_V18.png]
由当前11件STEP生成的CHB、C203与端接板装配图


新增输入板、两个阶梯垫柱和两个螺钉。旧965实例逐行保持；970件为源清单，本轮没有完成970件SolidWorks整机原生装配或连续动作验收。

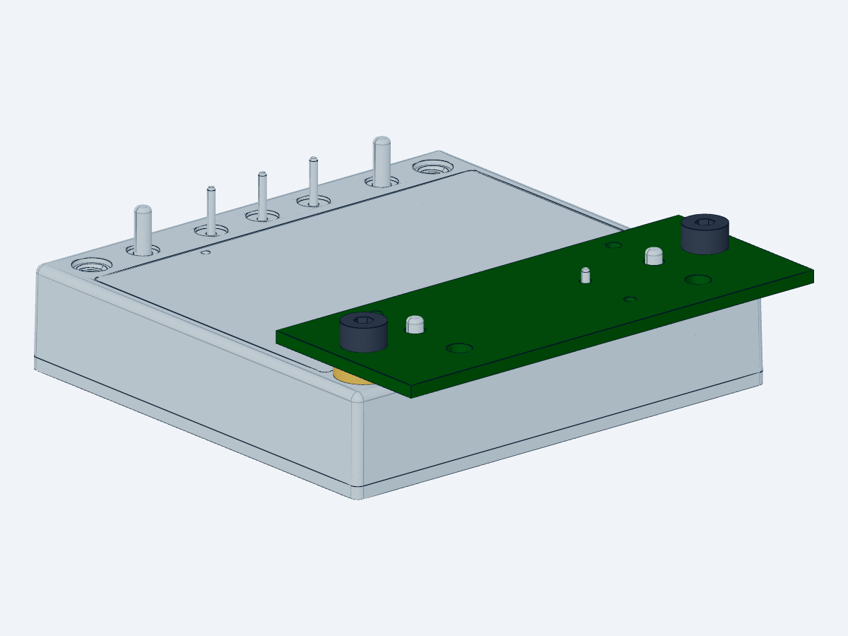
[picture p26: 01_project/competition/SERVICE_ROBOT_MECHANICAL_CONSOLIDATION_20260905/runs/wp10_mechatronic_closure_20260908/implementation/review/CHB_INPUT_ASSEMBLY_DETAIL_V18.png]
同STEP隐藏5个C203背景件后的6件端接细节


细节图隐藏5个C203背景件，仅影响查看。螺钉两端名义间距6.45mm；孔位公差、预紧与蠕变仍需验证。

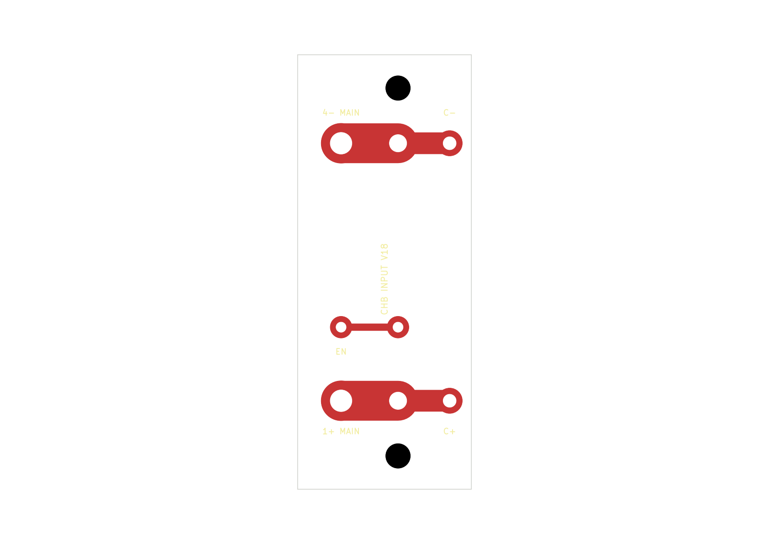
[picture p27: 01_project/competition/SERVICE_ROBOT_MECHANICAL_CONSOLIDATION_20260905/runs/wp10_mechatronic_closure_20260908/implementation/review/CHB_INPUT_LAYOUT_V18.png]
原生KiCad导出的CHB输入铜图


24×60×1.6mm，双面各70μm铜。成品孔和铜盘为项目尺寸，厂家没有给推荐数值。

## 仍需落实的导线与整机工作

C203两端孔已定义，下一步生成连续配对路线和保持结构，核查弯曲、端部、低电感与安装次序；同时补主馈/使能参考回线和C203单面NPTH工艺。电池/PMM、停止回生热动态和同修订推进ICD继续按原责任表推进。

主原理图源哈希未变，沿用已验证的ERC0/0及原4项忽略；本轮没有以空白板项目原理图重跑ERC。

原37行：13限定完成 / 19内部开放 / 4外部接口 / 1实物未执行

ID | 对象 | 状态 | 剩余设计
A01 | 705 三态固定姿态增量 | COMPLETE_SCOPED_SUBITEM | 此子项关闭；不代表承载连接或连续机构完成
A02 | R01 32 套连接的 128 标准件选型与材料模型 | COMPLETE_SCOPED_SUBITEM | 材料/标准选择子项完成；几何集成在 H02，连接承载在 A03
A03 | R01 与其余必需连接的有效啮合、防松、工具及承载 | INTERNAL_DESIGN_OPEN | 实际工具尚未选，夹层公差/不完整螺纹、预紧/防松和载荷验算未闭合；其余连接件不能继承 R01 选择
A04 | 六片太阳翼基板与边框实际固定 | INTERNAL_DESIGN_OPEN | 基板仍无孔、EDGE_INSERTS_TBD；板材/铺层、嵌件、紧固及粘接载荷路径未定
A05 | 电池、高功率支路、推进及状态传感器安装 | INTERNAL_DESIGN_OPEN | 新增电池及功率级安装未实现；推进受控安装面/端口未绑定；保持与状态检测的真实件未闭合
A06 | 责任件工程图、公差、处理及装配顺序 | INTERNAL_DESIGN_OPEN | 最终变化责任件同源工程图和全系统装配工艺未完成
B01 | 低功率 EPS 配置与负载限制合同 | COMPLETE_SCOPED_SUBITEM | 子项仅配置和限制定义，不证明全部能源链
B02 | P60/BPX 同修订线束、断路与充电保护 | EXTERNAL_INTERFACE_UNBOUND | 同配置针表/母板选件、保护回流/平衡/充电配套未绑定；仅按 NC 不等于整个组合兼容
B03 | 独立星上 360 W 机械臂完整受保护电源 | INTERNAL_DESIGN_OPEN | 电池充电/连接视向、全范围均流/BMS配合、瞬态、单故障、原理图/PCB/安装与热路径尚未完成
B04 | 84 CIC 的完整机电连接和温度电压 | EXTERNAL_INTERFACE_UNBOUND | 完整成形焊片外形、串接/阻断/绝缘/应变释放、胶材料及冷温 Voc 保证尚未关闭
B05 | 完整任务模式与轨道能源收支 | INTERNAL_DESIGN_OPEN | 示例轨道/姿态/日照/阴影及操作占空未绑定现任务；启动/峰值/制动/恢复全负载模型不完整
B06 | A3200 唯一正式供电支路 | INTERNAL_DESIGN_OPEN | 该范围不是所选 PDU 保证；启动/限流/热态接触电阻及 P1/FSI 实际互斥未闭合
C01 | GX11CAB 具体选择和正线切断拓扑 | COMPLETE_SCOPED_SUBITEM | 子项完成；不称全电隔离、不称辅助 NO 为镜像安全触点
C02 | 停止监督离线命令策略 | COMPLETE_SCOPED_SUBITEM | 仅命令策略；无 MCU 构建、实际驱动或安全时间证明
C03 | 独立停止链、线圈驱动/反馈/故障检测电路 | INTERNAL_DESIGN_OPEN | 纹波/启动/瞬态及15.7/13.5mV恢复裕度、Schmitt连续电压域阈值、棕断行为、MCU/母线健康、PCB热布局与全链100ms仍未闭合
C04 | 掉电可用回生能量去路与脉冲/平均热 | INTERNAL_DESIGN_OPEN | 真实组合体惯量/速度/重力项及电阻脉冲曲线、掉电吸收/过温处置、温升安装未闭合
C05 | 失扭矩承托及完整 GSE 防护 | INTERNAL_DESIGN_OPEN | 承托实体/传感器/额定载荷、AC/PE/应变释放、制动罩壳及 PCB 固定尚不完整
D01 | 推进公开资料锁版及必要条件排除 | COMPLETE_SCOPED_SUBITEM | 完成的是资料身份及条件排除；不构成实际推进能力
D02 | 具体推进模块的机械/电气/软件受控接口 | EXTERNAL_INTERFACE_UNBOUND | 总孔数/坐标/深度/保持载荷、实际喷口方向/命令映射/并发/推进器针表/CRC遥测与故障态仍未获得受控ICD
D03 | 推进实际任务与预算闭环 | INTERNAL_DESIGN_OPEN | 现任务矢量/平移许可/时间窗、最终 mass/COM 与真实 nozzle 未绑定；缺受约束分配和必要时域
D04 | 推进实际安装、维护与工作喷流 | INTERNAL_DESIGN_OPEN | 未给最终空置净空间、受控安装变换/保持载荷、工具和羽流路径
E01 | 现有系统 KiCad 与主 From–To 同源 | COMPLETE_SCOPED_SUBITEM | 保留2项抽象保护/开关后电源驱动ERC诊断，不加PWR_FLAG；ERC数量不代表功能覆盖
E02 | 独立 RS422 地面无源转接板 | COMPLETE_SCOPED_SUBITEM | 板级导体设计完成；罩壳、焊线卸载和成品工艺属于C05/E05，不是推进接口认证
E03 | MotorBridge 原始源与 DM 离线适配 | COMPLETE_SCOPED_SUBITEM | 未本机重编Rust；原生MIT编码/串口后端与硬件I/O未执行。ctypes布局仅匹配reprC声明，未在DLL内部探测布局
E04 | B601 DM 实际关节/端接及星上控制路径 | EXTERNAL_INTERFACE_UNBOUND | 公开参考不等于出货实机；方向/传动比/零位/机械限位/针位视向/固件与星上CAN后端仍未绑定
E05 | 全部必需线束三维路径/端接/裁线/保护 | INTERNAL_DESIGN_OPEN | 尚缺完整触点/工具配套、R≥120动态路由、夹紧载荷、弯曲/活动余量、连接器穿入与裁线长度
E06 | 必需状态检测、控制供电及真实系统原理图 | INTERNAL_DESIGN_OPEN | 供源动态与掉电证明、MCU电压域和实际健康观测、连接器/PCB及其他设备状态反馈未齐
F01 | 873 实例质量责任归属和 R01 子账 | COMPLETE_SCOPED_SUBITEM | 归属及数据入口完成；整B6014.5kg不可平均分配为各link，未知物性继续F02
F02 | 最终实例质量上下界、三态 COM/惯量与捕获组合 | INTERNAL_DESIGN_OPEN | B601逐link分布、设备包络/平均重量的真实惯性、全运动树/刚体分组及全星COM/I/推进剂状态仍未闭合
F03 | 星上导热/辐射及 GSE 对流热设计 | INTERNAL_DESIGN_OPEN | 电池、驱动、回生、电源、推进热路径/界面/工况/温升未实现完整计算
G01 | 六矩形面层太阳翼四段连续间隙 | COMPLETE_SCOPED_SUBITEM | 仅六块保守层包络、指定单关节四段；排除tab/框销/整星/臂/线束/柔性
G02 | 完整机构动作、机械臂释放/工作域、活动线束与维护 | INTERNAL_DESIGN_OPEN | 真实框销/锁定保持/整星/臂/tab/线束连续碰撞及装拆路径未覆盖；机械臂允许工作域未绑定
G03 | 当前结构载荷路径与分级强度/刚度/稳定性 | INTERNAL_DESIGN_OPEN | 当前板/支架/电池/推进/机械臂基座/保持连接的载荷、许用、公差与边界未统一验算
H01 | 705 三态可迁移原生包 | COMPLETE_SCOPED_SUBITEM | 此子项完成；搬移验证不等于在第二台机器实际测试，也不自动覆盖新增873候选
H02 | 太阳面层/铰链和R01联合原生增量 | COMPLETE_SCOPED_SUBITEM | 本轮增量交付子项关闭；全机电一致及未完成设计仍在H03和A-G
H03 | 全套机电 BOM/接口/制造数据一致与设计复现 | INTERNAL_DESIGN_OPEN | 停止PCB/安装件、全部真实线束/图纸/控制和推进接口及整机物性仍未齐；不能以子包完整性宣布全部完成
H04 | 原24项物理检验与后续到货/制造检查 | PHYSICAL_NOT_EXECUTED | 物理未执行独立记录；表中未绑定设计输入须先在A-G关闭，不能改名为到货检查清零

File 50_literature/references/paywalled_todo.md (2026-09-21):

# REORG-01-R 仍缺全文待办

生成日期：2026-07-22

当前总计：**1 条**。原 LIT-01 的其余付费/策略待办均由用户提供的合法本地副本解除；本表只描述“当前是否有本地全文”，不改变出版社访问属性。

没有绕过登录、机构订阅、验证码或付费墙。

| key | 标题 | DOI | 优先级 | 阻塞范围 | 合法人工处理说明 |
|---|---|---|---:|---|---|
| `gerstmayr2013ancfreview` | Review on the Absolute Nodal Coordinate Formulation for Large Deformation Analysis of Multibody Systems | [10.1115/1.4023487](https://doi.org/10.1115/1.4023487) | P0 | e15 ANCF 理论依据与模型选型来源闭环；不等同于当前 5% 交叉求解数值门 | 通过所属机构图书馆或作者/机构自存档合法取得并核验。 |

## 回填规则

1. 核对首页题名、作者、期刊与 DOI；
2. 保存为 `50_literature/pdf/04_flexible_ancf/gerstmayr2013ancfreview.pdf`；
3. 校验 `%PDF`、页数、SHA-256 与首页身份；
4. 更新 `manifest.yaml`、`refs.bib`、本表和 `landing_check.md`；
5. PDF 本身继续不入 Git。

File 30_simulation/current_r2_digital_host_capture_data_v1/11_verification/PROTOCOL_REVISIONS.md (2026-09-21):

# 协议修订记录（append-only）

## R1 — 标签分类学：终态 WAIT 的 episode 标签（Run1 崩溃触发）

- 现象：S07 INJ02a（软过期 WAIT）episode 以 `WAIT` 作数据集标签被 writer 硬拒（设计内 fail-closed）。
- 裁决：WAIT 是**运行时决策**（`terminal_decision` 合法取值），不是数据集标签；终态 WAIT 的 episode
  标 `NOT_EVALUATED` + `not_evaluated_reason`（保持窗内判据未渲染）。
- 性质：分类学澄清，不改变任何判据数值。Run1 产物隔离于 `12_results/episodes_QUARANTINED_run1_crash_wait_label/`。

## R2 — S02 收敛判据：舍入底板条款（Run2 FAIL 触发）

- 现象：Run2 三案例 rel_h_drift 均 ~1e-14（比 1e-9 门槛好 5 个量级），但预注册收敛阶拟合在舍入底板上
  病态（drift 序列非单调/比值无意义），`G_convergence_order` 判 FAIL → DH-G0 FAIL。
- 诊断：与 sim_11 v1.0 G4 同族——对不适定量做阶拟合。守恒残差在**每个** dt 都处于 1e-12 以下本身就是
  最强通过证据；此时阶拟合无信息量。
- 裁决（v2 判据，Run3 前冻结）：`rel_drift < 1e-12（全部扫掠 dt）→ PASS_AT_ROUNDOFF_FLOOR`；
  高于底板时仍要求 order ∈ [3.0, 5.5]。**1e-9 守恒门槛与 xcheck 门槛不变。**
- 性质：判据补充（底板条款），非放宽——底板 1e-12 比原门槛 1e-9 严 3 个量级。
  Run2 原样存档：`11_verification/_archive_run2/`、`12_results/_archive_run2/`。

## R4 — S02 收敛判据：成对底板语义（Run3 FAIL 触发，R2 的修正案）

- 现象：Run3 case1（arm_only, dt 扫掠 4e-3/2e-3/1e-3）rel_drift = [1.67e-12, 1.09e-13, 2.58e-14]——
  首值略高于 1e-12 底板，后两值深入底板。R2 条款要求"全部低于底板"才触发底板通过，于是对
  (1.09e-13→2.58e-14) 这对**舍入主导的数据**做了阶拟合（2.08 ∉ [3.0,5.5]）→ 判 FAIL。
- 诊断：R2 底板条款写得不完整。Roache 收敛分析常识：阶拟合只在**两个漂移都在底板之上**时有信息量；
  序列"进入底板"（末值 < 底板）本身就是收敛证据。
- 裁决（R4，成对语义）：
  1) 全部 < 底板 → PASS_AT_ROUNDOFF_FLOOR；
  2) 存在双双高于底板的相邻对 → 仅对这些"信息对"要求 order ∈ [3.0,5.5]；
  3) 无信息对且末值 < 底板 → PASS_ENTERED_ROUNDOFF_FLOOR；
  4) 其余 → FAIL。
  （case1 实际首对 (1.67e-12, 1.09e-13) 亦跨底板，非信息对 → 按 3) 通过；其 order=3.94 恰在 RK4 带内，
  记录为佐证不入判据。）**守恒门槛 1e-9 与 xcheck 1e-8 始终不变。**
- 性质：判据语义修正（阶拟合适用域收窄到有信息数据），不放宽任何数值门槛。
  Run3 v1 判据产物存档 `11_verification/_archive_run3/` 与 `12_results/archive_run3_r2clause/`。

## R3 — S03 名义步长：dt=1e-3 → 5e-4（Run2 饱和诊断触发）

- 现象：dt=1e-3 时 S03 出现 joint6 力矩打满（7.0 N·m cap）+ 动量漂移 0.117；dt=5e-4 时同场景
  taumax=0.020 N·m、漂移 1.2e-13、跟踪误差 3.2e-7 rad——纯数值失稳（最快 PD 关节模态超出 RK4 稳定边界），
  非物理结论。
- 裁决：S03 名义 dt=5e-4；dt=1e-3 运行**保留为预注册负见证**入 s03_summary
  （`negative_witness_dt_1e_3`），不删除不粉饰。
- 性质：数值配置修正 + 真实负结果保留。S03 无 pass gate，claim 仍为 DIAGNOSTIC_ONLY。

## R4 执行闭环 — 本地语义验证完成，时域复跑在预执行门 HOLD

- 中断恢复：确认生产 `scen_dynamics.py` 也已在 Run3 之后被编辑；Run3 旧 CPython 3.13 执行字节码先于任何 import/pytest 无损冻结。
- Run3 归档：`11_verification/_archive_run3/` 与 `12_results/archive_run3_r2clause/`，285 个文件、783797 bytes，源/目标 SHA-256 逐一一致；原 `DH-G0=FAIL` 与 S02 case1 负结果不改写。
- R2 路径勘误：本项目实际 Run2 结果路径是 `12_results/archive_run2_preprotocol/`，不是上文历史记录中的 `12_results/_archive_run2/`。
- R4 生产语义：唯一 helper 要求至少三个 coarse→fine 严格逐次减半点；单点/双点直接 `FAIL_INSUFFICIENT_REFINEMENT_POINTS`；只拟合双端均处于 floor 或以上的相邻对；进入 floor 必须在可测区一致下降；进入 floor 后反弹、倒序、重复或非 2:1 步长均 fail-closed。
- 测试：最终计数与源码 SHA 见 `R4_TARGETED_TEST.log`、`R4_FULL_TEST.log` 和 `R4_ARTIFACT_SHA256.csv`。中断快照中的测试内复制判定已由直接调用生产 helper 的负控替代；旧 13/13 项目基线覆盖未回归，但不声称中断期间的测试文件字节未被替换。
- 预执行裁决：`HOLD_FAIL_CLOSED`，Run4 未执行。阻断一为旧 runner 不支持版本化 output-root，保留的 Run3 活跃 episode 会导致部分覆盖后失败；阻断二为 S02/S03 都从未缩放的 `h_O=[angular;linear]` 六维范数派生指标：S03 标量没有单一合法 SI 单位，S02 的“相对”比值也依赖角/线分量的任意单位缩放，违反 UNIT_CONTRACT 的分列口径；阻断三为 case2/case3 只有单一 dt 点，不满足最终 R4 三点最低要求。
- 结果边界：Run3 S02 case1 数据用 R4 helper 只可得到 `PASS_ENTERED_ROUNDOFF_FLOOR_REEVALUATION_ONLY`；case2/case3 各只有一个 dt 点，按最终 fail-closed helper 为 `FAIL_INSUFFICIENT_REFINEMENT_POINTS`。因此没有“整个 Run3 反事实 PASS”，更不是 Run4 时域结果。最高状态为 `R4_REPEAT_REQUIRED`；父 Gate 未重发，`next_stage_authorized=false`，`release_credit=false`。
- R3 机制措辞收窄：两步长证据强烈支持时间离散失稳，但“最快 PD 模态已被证明跨越 RK4 稳定边界”仍缺闭环特征值/稳定域计算及独立求解器对拍，保留为待验证机制假设。

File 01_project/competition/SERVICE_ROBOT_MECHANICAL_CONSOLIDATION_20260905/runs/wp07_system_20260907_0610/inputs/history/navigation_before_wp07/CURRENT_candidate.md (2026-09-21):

# 项目文件整理与机械设计工作入口

更新：2026-09-06。日常入口为 [PROJECT_MAP](../../../PROJECT_MAP.md)，机械总装从 [WP03](../../../20_engineering/service_robot_wp03_spacecraft_body_r1/README.md) 进入。本页记录已执行整理和实际覆盖范围，原机械问题继续保存在 [issues.json](issues.json)。

## 本轮内部整理的实际结果

- **删除 33 份 Markdown**：31 份经内容比较后归并到 11 个保留入口，另 2 份与保留件完全同字节。仅新建 2 份合并文，其余使用已有文件。
- **删除 159 个可再生 Python 字节码**，源码全部保留并重新核对 SHA。限定审阅的 356 个缓存中，其余 197 个因证据绑定、版本/头差异或消费者范围未查清而保留。
- 共删除 **192 个文件、4 个空目录**。12 个另外已空的缓存目录因自动审批拒绝删除而保留，未修改访问权限。
- 修改了导航及已定位的消费者引用；原件均备份在已有 SQLite，不再生成同样内容的归档 Markdown 或压缩包。
- 整理后八域可枚举范围为 **53,176 个文件、6,731 个子目录**，根目录仍为 **19 项**。相比本轮开始净少 190 个文件（删 192、新增 2）。这些数量包含运行环境、第三方库和派生物，并非设计零件数；SQLite WAL/SHM 会随连接启停变化。

| 合并内容 | 现在阅读的位置 | 本轮删除源数 |
|---|---|---:|
| 任务背景、状态、研究问题、领域概念、架构决定与早期规划 | [背景与状态沿革](../../../10_research/knowledge_base/project_context/README.md)、[早期研究规划](../archive/EARLY_RESEARCH_PLAN_20260711_20260717.md) | 13 |
| 分散模块卡、旧仿真基线说明及同字节报告副本 | [模块索引](../../../30_simulation/module_cards/README.md)、[仿真入口](../../../30_simulation/README.md) | 12 |
| Stage 1 双语需求、建库说明、英文资源镜像及 Route-C 简报副本 | [Stage 1](../../../20_engineering/stage1_spacecraft_layout/README.md)、[工程入口](../../../20_engineering/README.md) | 6 |
| 旧补充文献迁移备注与 LibreCube 来源说明 | [文献入口](../../../50_literature/README.md)、[第三方来源入口](../../../80_third_party/README.md) | 2 |

旧 PL1 模块卡复制树检查被新合并结构取代后，消费者明确报告原复制范围为历史 HOLD；其余复制检查仍保留。没有把改目录后的检查伪装成原 15/15 结果。

## 哪些内容保留，以及为什么

- WP01/WP02 仍是 WP03 的输入，R2、历史模型、失败几何和科学负结果分别保留。原生 CAD、坐标、质量惯量 CSV 与科学 Gate 未在本轮修改，也未运行 CAD/动力学/控制程序。
- WP01/WP02/WP03 的 13,954 个 `__cadgen__` 文件包括图册消费者和包络诊断的来源；已有图片或 STEP 未证明它们可完整替代。
- 工程域剩余 11 个 ZIP 有不同哈希与授权/基线/失效原件职责；来源清单固定的 donor 副本也保留。两份 BIRDS 工作树包含独立 Git 状态，已标明主参考与历史镜像。
- A4 清单固定的适配器英文要求、研究状态 v4、R2 V1–V7 链及具名历史回执保留原始身份。历史记录中出现旧路径可用下述映射定位；原记录日期、数字和裁决不被无痕更新。

## 审阅覆盖与尚未完成的范围

本轮对全部可访问路径登记了角色和保留/删除理由，并给各已登记子目录记录审阅范围。**这不等于逐个文件都已完成专业全文或原生内容审查。** 删除 Markdown 的依据是具名的全文比较；字节码依据是源码、文件头及消费者检查；大量其余项仅有既有提取记录或元数据/用途分类。

仍有 **10 个 pytest 临时子树拒绝访问**；原生 CAD 内部装配引用、PDF 图形、动态消费者以及未精读正文继续标为待审阅。统一账本中的 `previous_read_status` 不因本轮分类被升级。最终追加的独立复核因额度中断未完成；根代理完成最终恢复、路径和执行账核验，前面已完成的独立比较与检查分别保留。

自动审批两次拒绝删除已核实为空的缓存目录，返回仅为 `blocked by policy`。12 个目录保留；此记录不表示文件删除失败，也不作为清空其他目录的授权。

## 逐文件查询与恢复

使用唯一 [full_project_catalog.sqlite](runs/loop0_20260905/screening/full_project_catalog.sqlite)：

- `domain_inventory` / `domain_subtree_review`：原编目、逐项处置、目录审阅范围；新合并文件已补登记。
- `domain_actions` / `domain_current_locations`：本轮原路径、动作、保留内容位置、执行状态及恢复阶段；历史引用通过这里追溯。
- `snapshots`：删除/修改前原始字节，以 zlib 存储。按动作中的 `snapshot_stage` 解压后核对 SHA256 和长度，再按需恢复。
- `reviews` / `meta`：内容比较、消费者检查、独立验证与当前范围；`ENGINEERING_PYC_READONLY_REVIEW_20260906` 是字节码逐件检查记录。

[run_manifest](run_manifest.json) 与 [dependency_manifest](dependency_manifest.json) 的旧 WP03 字段保留历史身份；新增 `domain_internal_consolidation_20260906` 记录本轮结果。文件快照属于恢复凭据，不是新的设计版本。

## 前一轮根目录整理（独立范围）

此前根目录 45→19 项，19 份 Markdown 合为 2 份，77 个独有文件归入业务域；删除 24 文件和 18 空目录。原启动/入驻内容进入[根部历史综述](../archive/ROOT_HISTORY_20260729_20260810.md)，原 knowledge 方法进入[结构方法](../../../10_research/knowledge_base/spacecraft_mechanical_design/legacy_structure_methods_20260728.md)。明细在 `root_layout_actions`，恢复阶段为 `BEFORE_ROOT_PHYSICAL_CONSOLIDATION_20260906`；更早的 12 文件缓存清理也单独记账，不重复计入本轮 192 文件。

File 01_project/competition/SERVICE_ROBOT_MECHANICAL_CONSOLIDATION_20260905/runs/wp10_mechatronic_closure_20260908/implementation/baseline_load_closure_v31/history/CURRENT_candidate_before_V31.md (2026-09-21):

## WP10 电气—热控—推进联合候选（2026-09-10）

最新增量入口：[联合设计查看页](runs/wp10_mechatronic_closure_20260908/implementation/coupled_closure/REVIEW.html) / [设计与验证报告](runs/wp10_mechatronic_closure_20260908/implementation/coupled_closure/README.md) / [机器状态](runs/wp10_mechatronic_closure_20260908/implementation/coupled_closure/DELIVERY_STATUS.json)。本候选绑定V26电气/PCB、V21的974实例计划及其真实来源；207位号、673针脚网络统一，35项针对性测试通过。新增8种项目零件的参数化几何，两套局部STEP共17个有效实体；未替换原生整星总装。

**完整电气、热控与推进闭环仍未达成。** 新输入板热量接入拟议热路后，CHB连续工况壳温107.060°C超过105°C限制；新模块候选安装位置经真实STEP检查三态各18处交叠，已拒绝。实际任务、推进受控ICD及974构型逐link物性仍有缺口。测试与局部几何检查不赋予整机制造、上电或飞行放行。下方旧入口按各自记录日期保留。

---

## WP10 当前活动改件候选（2026-09-08）

`runs/wp10_mechatronic_closure_20260908/implementation/`：公开模块选择、DM运动树绑定、单变换器安装板和电源子图。交付状态为有界设计增量；整机机电/通电/制造均未放行。

[查看本轮](runs/wp10_mechatronic_closure_20260908/implementation/REVIEW.html)

---

# 当前工程入口：WP10 机电补全与研究交接

2026-09-08：从[本轮交付说明](runs/wp10_mechatronic_closure_20260908/README.md)与[统一查看页](runs/wp10_mechatronic_closure_20260908/REVIEW.html)进入。修订系统原理图99器件/97网/72外部接线，停止子页76器件；三态873实例SI入口与材料模型惯性补充见本轮数据包。原生873叶SolidWorks三态包继承上一封存版本，本轮没有重建原生总装。

**完整可装配工程样机的全部机电设计尚未交付。** 仍有23项开放工作包，含高功率能源链、推进受控ICD、真实运动link物性和驱动、完整线束及热/强度/动态停止等。可以进入声明假设的模型/验证与理论研究准备，并由动力学载荷反向支持工程收束；本轮没有执行控制、强化学习或实物动作，旧科学PASS不转移到当前873构型。

本轮[机器判定](runs/wp10_mechatronic_closure_20260908/results/DELIVERY_DECISION.json)和[研究来源审计](runs/wp10_mechatronic_closure_20260908/research_intake/RESEARCH_READINESS.md)分别记录工程缺口与107条历史原始SHA中的29条漂移；不改写旧Gate结论。

下方历次入口原样保留，其中“当前/本轮”均属于记录时刻。

---

# 当前工程入口：WP09R 原生装配、电气与推进设计增量

2026-09-08：从 [本轮交付说明](runs/wp09_interfaces_20260907_1525/system_completion/README.md) 与 [可视化查看页](runs/wp09_interfaces_20260907_1525/system_completion/REVIEW.html) 进入。三态原生 SolidWorks 各 873 叶零件、10 固定容器，19 个唯一子装配；新增太阳面层、修订叠层机构与 R01 标准件。实际保存、冷重开及搬迁见 [原生交付回执](runs/wp09_interfaces_20260907_1525/system_completion/results/NATIVE_DELTA_DELIVERY.json)。原 705 组件便携包保留。

实际停止电路已并入系统两页原理图：94 元件/96 网/72 条外部主表连接、191 项连接核验；[主接线表](runs/wp09_interfaces_20260907_1525/system_completion/ecad/MASTER_FROM_TO.csv) 与 [分层 BOM](runs/wp09_interfaces_20260907_1525/system_completion/ecad/MASTER_BOM.csv) 为当前子版，父版同名文件保留历史身份。真实官方 MotorBridge DLL 完成18项边界ABI检查，DM公开电机型号与ID已绑定，原生串口/MIT编码未执行。推进源侧针位与安装螺纹已修正，模块受控ICD仍未绑定。

完整机电系统详细设计仍未完成：辅助供源与停止PCB、星上高功率支路、回生、推进受控接口、完整线束及热/强度/整机动作仍有开放设计责任。现行 [机器状态](runs/wp09_interfaces_20260907_1525/system_completion/results/DELIVERY_STATUS.json) 保留未满足条件与原24项未执行物理检查。原85文件电气/DM参考包、47网一致/29项Python历史验证均保留原身份，不与本轮18项原生ABI检查混记。

下方历次入口原样保留，其中“当前/本轮”均属于记录时刻。

---

# 当前工程入口：WP09R 成熟模块复用与结构候选收束

2026-09-07：从[本轮完整交付](runs/wp09_interfaces_20260907_1525/reuse_closure/README.md)与[可视化查看页](runs/wp09_interfaces_20260907_1525/reuse_closure/REVIEW.html)进入。三态SolidWorks各705组件/1086预期实体已完成本轮增量验收：全组件身份/哈希/变换冷读，新5实体实读，旧1081实体继承父本证据。另有独立RS422地面转接板原生SLDPRT。

实际KiCad系统含70连接记录/117端点/47网络，派生地面板ERC/DRC/板图一致性零违规；系统ERC保留1项停止链供电边界错误。完成29项真实DM协议离线测试、19项电源参数反例及36项推进源/需求核对。K1、P60板位和BPX针位冲突已定点修订；现有EPS不能承担360W机械臂在轨负载，真实推进ICD/功能仍开放。

本轮固定姿态结构候选可冻结；整机完整机械/电气功能、连续动作、制造与飞行放行仍未完成。详见[机器状态](runs/wp09_interfaces_20260907_1525/reuse_closure/results/DELIVERY_STATUS.json)。下方历史入口原样保留，“当前/本轮”均属于其记录时间。

---

# 当前工程入口：WP09F 电气、推进与地面端口候选

2026-09-07：从 [本轮候选交付包](runs/wp09_interfaces_20260907_1525/functional_closure/README.md) 查看完整选型与针位报告、23条导体记录、四张接线原理图、条件电气/推进计算和已通过冷回读的5件SolidWorks端口局部装配。采用用户指定的Seeed reBot-DevArm公开DM基线，未冒充实机出货核验。

局部新原生装配通过不等于整星增量通过。本轮705组件/1086预期实体三态增量未验收，SERVICE保存文件的冷读恢复受内存保护阻断，另两态尚未生成；**整星仍使用下方父版已验证的701组件三态**。已放行电路0，实物检查0/24，实际推进任务能力UNKNOWN。具体开放项和来源见[设计报告](runs/wp09_interfaces_20260907_1525/functional_closure/docs/FUNCTIONAL_DESIGN_REPORT_ZH.md)，机器状态见[DELIVERY_STATUS](runs/wp09_interfaces_20260907_1525/functional_closure/results/DELIVERY_STATUS.json)。

以下父版及历史记录原样保留，其中“本轮/当前”属于记录时的范围。

---

# 当前机械工程入口：WP09 共享舱、推进与DM接口整合

2026-09-07：从 [本轮交付说明](runs/wp09_interfaces_20260907_1525/README.md) 查看3套SolidWorks固定姿态总装，每套701组件/1082几何实体；619组件继承，82实例新增/替换，共享21个新原生零件。服务态全部实体实读，停放/释放态新82实体实读、旧1000实体依冻结WP08证据哈希绑定；全部姿态组件身份/文件哈希/变换已核验。

B601已确认DM，工程样机采用外置RSP-500-24；BPX 8S/P60用于低功率支路。共享舱布局、非承压推进托架与两条静态线束路线已纳入总装。整机机械、电气、制造和飞行放行仍开放；真实端接、设备固定、DM出货机械修订与拆盖/工具验证见[关闭项与开放项](runs/wp09_interfaces_20260907_1525/docs/CLOSURE_DELTA_AND_OPEN_ITEMS_ZH.md)。完整电气回路仍为0。

机器状态见[DELIVERY_STATUS](runs/wp09_interfaces_20260907_1525/results/DELIVERY_STATUS.json)，文件完整性见[FINAL_INTEGRITY](runs/wp09_interfaces_20260907_1525/results/FINAL_INTEGRITY.json)。以下为历史入口，表述属于当时记录。

---

# 当前机械工程入口：WP09 电气与推进局部设计

2026-09-07：从 [WP09 交付说明](runs/wp09_electro_propulsion_20260907_1350/README.md) 查看三套局部 STEP，共44实体；其中 A3200 与 MiPS 的28件原生零件、2套 SolidWorks 固定装配通过冷重开与材料回读。电池源STEP检查通过，沉头螺钉原生转换仍为HOLD。当前状态见 [DELIVERY_STATUS](runs/wp09_electro_propulsion_20260907_1350/results/DELIVERY_STATUS.json)。

[电气与推进机械工作包](runs/wp09_electro_propulsion_20260907_1350/docs/ELECTRO_PROPULSION_MECHANICAL_WORK_PACKAGE_ZH.md) 给出设备实选、EPS/电池/推进共享舱调整、机械臂供电与保持/热/线束接口的后续工作。局部模型未合入WP08，整星机械、电气和制造放行仍未完成。

现有整星三态仍从 [WP08](runs/wp08_retention_delta_20260907_1228/README.md) 查看，保留每态625实例及后肋局部未回装状态。

以下为历史入口，表述属于当时记录。

---

# 当前机械工程入口：WP08

2026-09-07：从 [WP08 实际交付说明](runs/wp08_retention_delta_20260907_1228/README.md) 查看三态 SolidWorks 装配、后肋局部实体及检查记录。两站保持器已回装，每态625实例/1006实体；后肋11实例局部连接已验证但尚未回装整机。

整星机械与电气尚未完成。后续具体实体任务见 [下一批机械执行单](runs/wp08_retention_delta_20260907_1228/docs/NEXT_MECHANICAL_EXECUTION.md)。WP07与更早结果、失败记录及原问题账本继续保留。

以下为此前入口与文件整理历史，其中“当前/本轮”表述仅属于当时记录。

---

# 项目文件整理与机械设计工作入口

更新：2026-09-07。当前机械与机电接口审阅从 [WP07 交付说明](runs/wp07_system_20260907_0610/README.md) 进入；其中列出实际生成文件、原生回读、局部几何检查、参考 PCB 及尚未关闭的接口。

本轮为工程样机候选执行，不表示整机机械、电气、实物装配或制造放行完成。原 17 项问题记录保持原样，新增执行链接见 [issues.json](issues.json) 的 `wp07_execution`。

以下保留 2026-09-06 文件整理记录；其“本轮”及未运行 CAD 等表述只属于当时整理范围。

更新：2026-09-06。日常入口为 [PROJECT_MAP](../../../PROJECT_MAP.md)，机械总装从 [WP03](../../../20_engineering/service_robot_wp03_spacecraft_body_r1/README.md) 进入。本页记录已执行整理和实际覆盖范围，原机械问题继续保存在 [issues.json](issues.json)。

## 本轮内部整理的实际结果

- **删除 33 份 Markdown**：31 份经内容比较后归并到 11 个保留入口，另 2 份与保留件完全同字节。仅新建 2 份合并文，其余使用已有文件。
- **删除 159 个可再生 Python 字节码**，源码全部保留并重新核对 SHA。限定审阅的 356 个缓存中，其余 197 个因证据绑定、版本/头差异或消费者范围未查清而保留。
- 共删除 **192 个文件、4 个空目录**。12 个另外已空的缓存目录因自动审批拒绝删除而保留，未修改访问权限。
- 修改了导航及已定位的消费者引用；原件均备份在已有 SQLite，不再生成同样内容的归档 Markdown 或压缩包。
- 整理后八域可枚举范围为 **53,176 个文件、6,731 个子目录**，根目录仍为 **19 项**。相比本轮开始净少 190 个文件（删 192、新增 2）。这些数量包含运行环境、第三方库和派生物，并非设计零件数；SQLite WAL/SHM 会随连接启停变化。

| 合并内容 | 现在阅读的位置 | 本轮删除源数 |
|---|---|---:|
| 任务背景、状态、研究问题、领域概念、架构决定与早期规划 | [背景与状态沿革](../../../10_research/knowledge_base/project_context/README.md)、[早期研究规划](../archive/EARLY_RESEARCH_PLAN_20260711_20260717.md) | 13 |
| 分散模块卡、旧仿真基线说明及同字节报告副本 | [模块索引](../../../30_simulation/module_cards/README.md)、[仿真入口](../../../30_simulation/README.md) | 12 |
| Stage 1 双语需求、建库说明、英文资源镜像及 Route-C 简报副本 | [Stage 1](../../../20_engineering/stage1_spacecraft_layout/README.md)、[工程入口](../../../20_engineering/README.md) | 6 |
| 旧补充文献迁移备注与 LibreCube 来源说明 | [文献入口](../../../50_literature/README.md)、[第三方来源入口](../../../80_third_party/README.md) | 2 |

旧 PL1 模块卡复制树检查被新合并结构取代后，消费者明确报告原复制范围为历史 HOLD；其余复制检查仍保留。没有把改目录后的检查伪装成原 15/15 结果。

## 哪些内容保留，以及为什么

- WP01/WP02 仍是 WP03 的输入，R2、历史模型、失败几何和科学负结果分别保留。原生 CAD、坐标、质量惯量 CSV 与科学 Gate 未在本轮修改，也未运行 CAD/动力学/控制程序。
- WP01/WP02/WP03 的 13,954 个 `__cadgen__` 文件包括图册消费者和包络诊断的来源；已有图片或 STEP 未证明它们可完整替代。
- 工程域剩余 11 个 ZIP 有不同哈希与授权/基线/失效原件职责；来源清单固定的 donor 副本也保留。两份 BIRDS 工作树包含独立 Git 状态，已标明主参考与历史镜像。
- A4 清单固定的适配器英文要求、研究状态 v4、R2 V1–V7 链及具名历史回执保留原始身份。历史记录中出现旧路径可用下述映射定位；原记录日期、数字和裁决不被无痕更新。

## 审阅覆盖与尚未完成的范围

本轮对全部可访问路径登记了角色和保留/删除理由，并给各已登记子目录记录审阅范围。**这不等于逐个文件都已完成专业全文或原生内容审查。** 删除 Markdown 的依据是具名的全文比较；字节码依据是源码、文件头及消费者检查；大量其余项仅有既有提取记录或元数据/用途分类。

仍有 **10 个 pytest 临时子树拒绝访问**；原生 CAD 内部装配引用、PDF 图形、动态消费者以及未精读正文继续标为待审阅。统一账本中的 `previous_read_status` 不因本轮分类被升级。最终追加的独立复核因额度中断未完成；根代理完成最终恢复、路径和执行账核验，前面已完成的独立比较与检查分别保留。

自动审批两次拒绝删除已核实为空的缓存目录，返回仅为 `blocked by policy`。12 个目录保留；此记录不表示文件删除失败，也不作为清空其他目录的授权。

## 逐文件查询与恢复

使用唯一 [full_project_catalog.sqlite](runs/loop0_20260905/screening/full_project_catalog.sqlite)：

- `domain_inventory` / `domain_subtree_review`：原编目、逐项处置、目录审阅范围；新合并文件已补登记。
- `domain_actions` / `domain_current_locations`：本轮原路径、动作、保留内容位置、执行状态及恢复阶段；历史引用通过这里追溯。
- `snapshots`：删除/修改前原始字节，以 zlib 存储。按动作中的 `snapshot_stage` 解压后核对 SHA256 和长度，再按需恢复。
- `reviews` / `meta`：内容比较、消费者检查、独立验证与当前范围；`ENGINEERING_PYC_READONLY_REVIEW_20260906` 是字节码逐件检查记录。

[run_manifest](run_manifest.json) 与 [dependency_manifest](dependency_manifest.json) 的旧 WP03 字段保留历史身份；新增 `domain_internal_consolidation_20260906` 记录本轮结果。文件快照属于恢复凭据，不是新的设计版本。

## 前一轮根目录整理（独立范围）

此前根目录 45→19 项，19 份 Markdown 合为 2 份，77 个独有文件归入业务域；删除 24 文件和 18 空目录。原启动/入驻内容进入[根部历史综述](../archive/ROOT_HISTORY_20260729_20260810.md)，原 knowledge 方法进入[结构方法](../../../10_research/knowledge_base/spacecraft_mechanical_design/legacy_structure_methods_20260728.md)。明细在 `root_layout_actions`，恢复阶段为 `BEFORE_ROOT_PHYSICAL_CONSOLIDATION_20260906`；更早的 12 文件缓存清理也单独记账，不重复计入本轮 192 文件。

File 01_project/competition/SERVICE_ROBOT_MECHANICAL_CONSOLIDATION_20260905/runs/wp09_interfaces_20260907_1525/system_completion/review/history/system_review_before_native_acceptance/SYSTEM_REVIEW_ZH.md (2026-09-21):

# WP09R A—H 系统设计验收复核

复核快照：2026-09-07T12:40:17.607392+00:00。当前整机详细设计不能判为完成。现有已通过子项保持有效；本记录把未实施的设计、受控接口不足和未执行的实物检验分别记录，不能用其中一类替代另一类。

本次有限矩阵为 37 个工作包：已完成的限定子项 12，内部设计未闭合 19，外部接口未绑定 4，原生增量进行中 1，独立物理未执行记录 1。未闭合设计工作包 24；这些是工作包计数，不是功能完成比例。

[逐项验收矩阵](SYSTEM_ACCEPTANCE_MATRIX.csv)列出每项已有证据、剩余设计、责任角色、所需输入、具体操作和关闭证据。[机器复核](../results/SYSTEM_ACCEPTANCE_REVIEW.json)绑定本次读取文件的 SHA256。此记录只供当前主交付合入，不创建另一个 CURRENT 或系统主状态。

## 可保留的实际完成信用

- **705 三态父本增量与可迁移包已通过。** 原生705身份/变换成立；1086实体口径仍为父轮5新实体实读及1081继承。当前portable包508唯一零件、3总装，两个真实存储位置各三态冷重开，零外部依赖、ZIP CRC通过。曾发生长路径缺引用，解压应保持完整路径<250字符；没有在第二台电脑实测。
- **R01标准件和质量模型已落实。** 128实例、32套连接、4类具体选型不再是未选；修正代理钢材质量约0.05197845kg。它是无螺纹/部分倒角等细节的模型，非供应商单位质量；全载荷/预紧/防松与实际工具仍须验算。
- **六板四段展开取得连续包络证明。** 1548二分节点、776完整区间，下界0.30064349mm；原3mm轴距、原三段顺序和仅中点检查的负例均被检出。范围仅六矩形板和有界面层，排除焊片、框销、整星、机械臂和线束。
- **实际电气及软件子项可继承。** KiCad系统70连接/117端点/47网络对应；独立RS422板的限定检查通过；MotorBridge29项Python/假ABI测试与本轮停止策略13项真实运行。Rust本体、实际硬件驱动与控制时间未被这些测试执行。
- **705质量责任已100%归属。** R01补入后仍有388实例/29个owner缺数值质量；705账不自动覆盖新增168层或新的电源推进设备，完整整星质量/COM/惯量仍无结果。

## 不能移入“到货后检查”的内部设计

以下不是等待实物试验的成品设计；它们需要完成设计源、计算和接口修改。

|责任包|当前必须补完的具体输出|关闭所依赖的输入与责任|
|---|---|---|
|A03–A06|真实载荷连接、公差与防松；六叶板嵌件/保持；新增电池、功率级、推进和传感器安装；同源图纸与装配路径|机械团队使用最终器件安装面、材料/许用和载荷，不能用 fixed=true代替|
|B03/B05/B06|完整独立储能—充电—稳压—保护—机械臂电路；真实任务能源账；A3200一种正式供电|电源团队绑定电池ICD/器件保证界、任务工况、DM母线与启动条件|
|C03–C05|K1驱动PCB、独立允许/看门狗/反馈与复位；失电/过温回生去路；承托与完整GSE防护|电气/机械/热团队绑定停止时间、残余能量、夹钳/电阻及保持件的适用性能|
|D03/D04|真实喷口受约束分配、脉冲/并发/禁喷/时间/能源联合验证；实际舱位、安装和喷流|推进团队在同版ICD、当前mass/COM与任务H向量/平移/预算下计算|
|E05/E06|全部真实端点原理图、状态反馈和星上控制路径；每束线材/端子/工具/夹点/三维弯曲/活动余量/下料|电气/线束团队沿唯一MASTER_FROM_TO修订，7.5mm缆按实际允许弯曲设计|
|F02/F03/G02/G03|最终质量/惯量及不确定性、导热/辐射、实际运动/线束连续扫掠、真实载荷路径分级强度|各owner先给来源有界的质量/材料/热/机构数据，分析团队以当前CAD和判据验算|
|H02/H03|当前联合原生增量实际三态冷读、完整五组机电交付一致与可复现包|唯一writer实际输出；root核验后更新主状态，不能用本快照的计划873/1254代替结果|

## 最小外部资料与已识别的硬约束

1. **推进：一个实际C-POD配置的四类受控文件。** 完整订货/硬件/固件适用性，机械ICD及喷口坐标方向/指令映射，电气配对视向/针表/功耗时序，以及帧/CRC/命令/遥测/并发/最小脉冲。两份同PN同Rev参数表相互冲突，不可择优拼接。Owner已有可访问资料时可直接绑定；得到ICD之后仍须完成D03/D04。
2. **EPS/高功率储能：同配置接线与保护保证。** P60/BPX pin14冲突、充电/保护回流及选件必须整体闭合；MB2590示意图不足以定义完整配对面/充电使能/保护。A3200所要求源端范围不是PDU已保证。
3. **AZUR 81442：ZP0004289成形图或STEP。** 原厂说明40.15x80.15mm仅为玻璃外廓，焊片可越界。现84层代理不能充当完整CIC。得到资料后需真正完成串接、绝缘、胶材、热胀与折叠包络。
4. **DM：同版接口与关节配置。** B601是DM这一点已明确，但每关节型号/方向/传动/零位/工作限位、针位/端接/固件与交付原生ABI尚未逐项绑定。不能把公开协议缩放限值当机械允许值。

同时保留三个明确矛盾：单MB2590在20V时理想功率仅250W，小于360W；双电池总功率必要条件通过仍不等于均流/充电/热和安装闭合。TPS3431当前170–230ms设置不满足0.1s故障分断要求，必须修改实际设计。紧凑C-POD平衡力偶沿用历史54.734767g预算时角冲量上界1.82586Nms，仍小于3.65099Nms；该必要条件不得推广为所有允许平移/姿态机动都不可行，也不能静默改任务预算。

根任务正在独立完成 `electrical_reference/package` 的原样ECAD/DM源复制与迁移目录复验。该项以 `results/ELECTRICAL_REFERENCE_DELIVERY.json` 的真实结果为准；本快照不给尚未完成的导出信用。即使复验通过，也只关闭交付可迁移子项，不能增加新电路/完整电气功能信用或关闭H03的全部要求。

## 实物执行单独保留

已实际读取父本两份线束检验表共24行，execution_status全部NOT_EXECUTED。尚未采购、加工、接电、驱动、刷写、承压或推力试验；本复核也没有CAD/COM/OCC调用。表内决定设计能否成立的未知输入仍归A—G责任，不借物理未执行清零。

本次复核中A—H均仍有必需设计工作包，不能输出MECHATRONIC_SYSTEM_DETAILED_DESIGN_COMPLETE，也不能以局部通过率替代。原生增量仍在执行，root须依据其最终回执单独合入本快照之后的新信用；本记录不宣称当前阶段已经结束。

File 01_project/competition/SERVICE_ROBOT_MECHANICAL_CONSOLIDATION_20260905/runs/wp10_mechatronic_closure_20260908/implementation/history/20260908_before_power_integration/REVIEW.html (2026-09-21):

WP10 / 同一工作包的活动候选 / 2026-09-08

# 公开选型已经落到源文件和机械改件

本轮补齐机械臂名义运动树，选定三个电源模块候选，生成单变换器安装板与引脚电气子图。

交付状态：设计增量可查看，整机机电闭环仍开放。
新电源尚未接入原99位号电气系统，也尚未安装进873组件总装。不能据此通电、制造或宣称飞行适用。

## 当前选型决定

角色 | 候选 | 选择理由 / 当前边界
独立高功率储能 | RRC3570-4 / 110338 | 复用厂家保护电池包；最低端电压、可用任务能量和整舱安装待验证。
充电与电源路径 | RRC-PMM35 / 110297 | 厂家配套智能充电；20 A瓶颈、每针10 A、六针图示需按具体修订落实。
机械臂变换器 | CHB500W-24S24N ×1 | 单模块消除双i7C均流依赖；开路关闭，回灌保护与停止板动态兼容尚未完成。

选型BOM完整决策功率场景计算中文设计说明与来源

## 实际厂家件＋新安装板

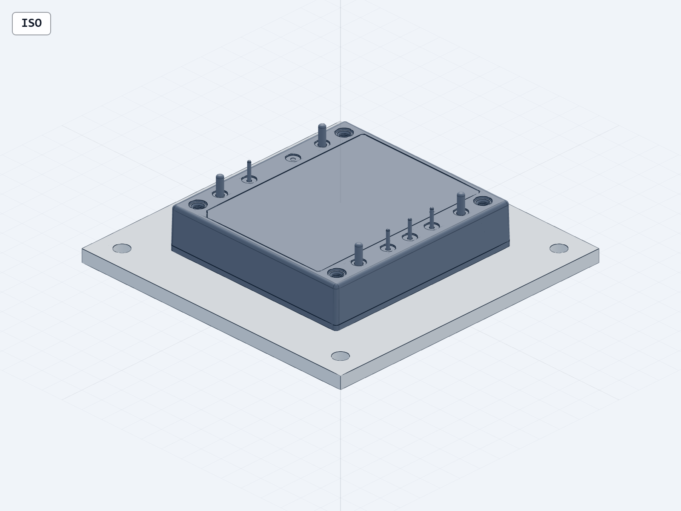
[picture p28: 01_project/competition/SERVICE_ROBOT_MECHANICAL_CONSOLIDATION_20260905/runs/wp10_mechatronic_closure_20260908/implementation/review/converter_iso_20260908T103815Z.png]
厂家CHB500W STEP与新90毫米安装板


安装件是新责任设计；厂家细节原样复用。0.2 mm导热界面为设计分配，尚不代表选定垫片或热阻合格。

旋转查看装配 (http://127.0.0.1:3245/F:/China%20Graduate%20Future%20Flight%20Vehicle%20Innovation%20Competition/01_project/competition/SERVICE_ROBOT_MECHANICAL_CONSOLIDATION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)下载装配STEP

## 可导入SolidWorks的责任件

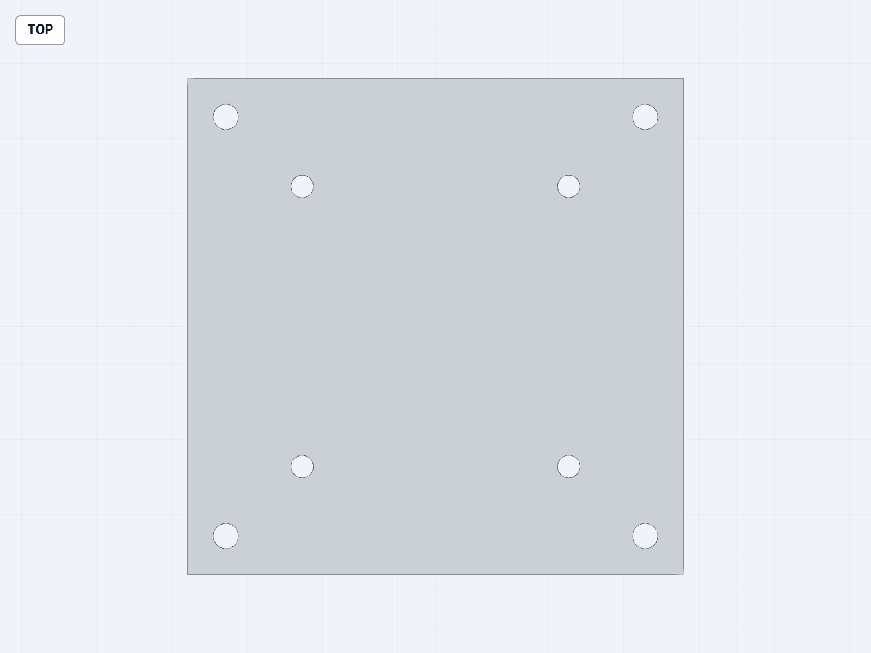
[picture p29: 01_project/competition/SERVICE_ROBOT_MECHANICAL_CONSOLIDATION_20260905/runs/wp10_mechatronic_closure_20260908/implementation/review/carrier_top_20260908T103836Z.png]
八孔90x90x4毫米安装板


板厚4 mm；器件孔距48.3×50.8 mm；承力接口76×76 mm。八孔与厚度已复核，承力接口还需整星验证。

查看安装板 (http://127.0.0.1:3245/F:/China%20Graduate%20Future%20Flight%20Vehicle%20Innovation%20Competition/01_project/competition/SERVICE_ROBOT_MECHANICAL_CONSOLIDATION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)下载安装板STEP

## 电源引脚子图

8个真实变换器引脚，本地sense，独立输入与输出回流，Trim明确空接；输入保护与输出回生为开放边界。ERC保留2项未供源诊断。

查看电气PDF可编辑KiCad引脚与网络PMM图示端点

展开实际电气图

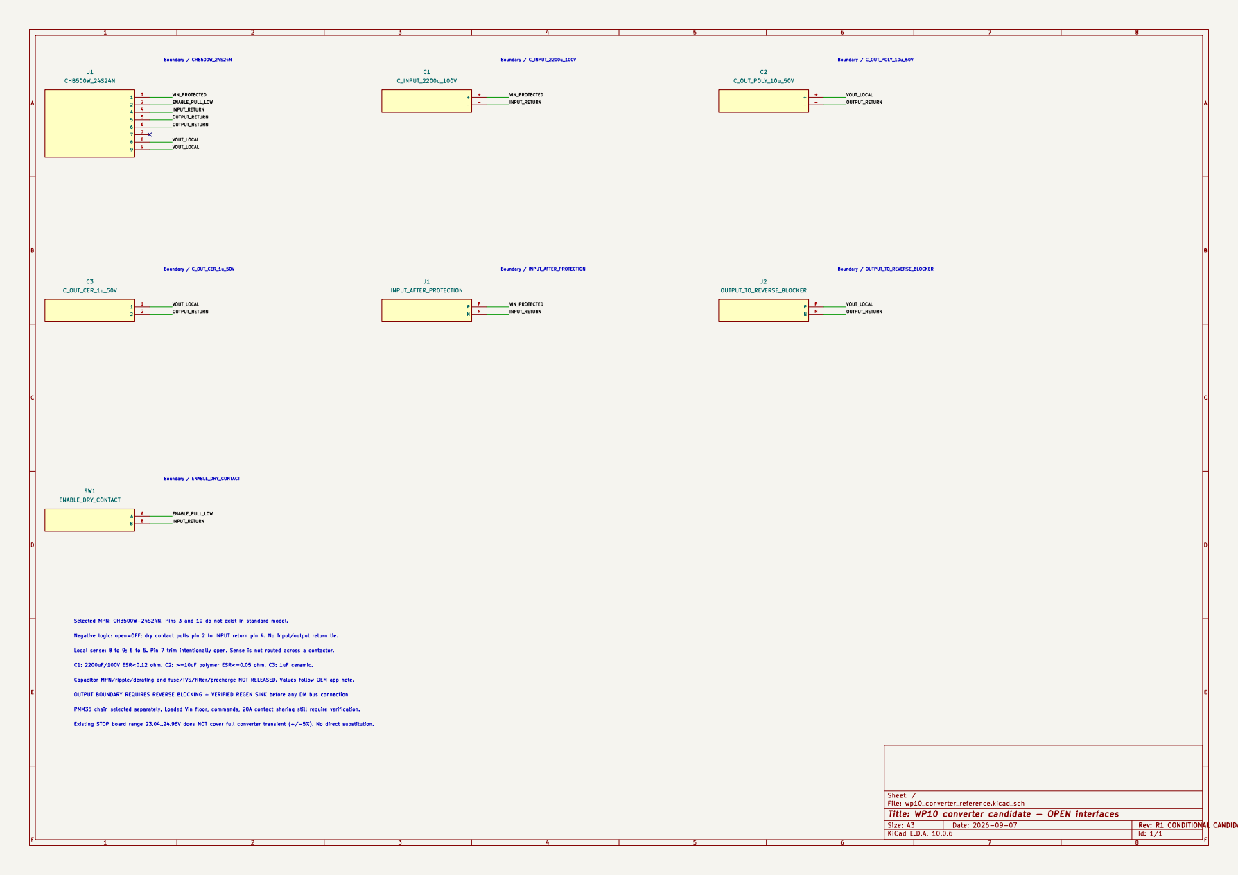
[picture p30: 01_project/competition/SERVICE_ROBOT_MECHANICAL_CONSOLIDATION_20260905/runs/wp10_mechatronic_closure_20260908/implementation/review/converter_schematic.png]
本轮KiCad实际导出


## B601 DM运动树已绑定

当前10个刚体、9条关节与官方历史版本匹配。94项来源/姿态检查通过，三态最大FK矩阵残差2.22e-16。夹爪按单电机名义同步关系登记；实物零位、齿条换算及逐link惯性保持未测。

状态 | 六关节 / ° | 双指位移 / m
service | 0, -80, -70, 30, 0, 0 | 0.015 / 0.015
parking / released | 0, -30, -60, 40, 0, 0 | 0.015 / 0.015

来源与运动树更新后的873参数包原873装配与电气父本

## 尚需完成的具体设计

1. 20 A路径的低电量能力、预充/保险/滤波、触点分流及充电功率调度。
2. 反向阻断、回生能量吸收与独立停止供源。变换器瞬态±5%不覆盖旧停止板输入合同。
3. 电池/PMM安装、整舱布置与导热路径；逐运动link物性、完整载荷及连续线束运动。
4. 推进模块受控ICD：同一修订的针序、指令、喷口坐标、安装和并发点火限制。

内存保护已执行并仅清理任务进程。厂商细节完整自相交检查未完成，后续轻量拓扑、正体积与尺寸检查完成；没有将未完成项写成通过。

原工作表与新增证据机器交付判定内存处置下载本轮源文件包

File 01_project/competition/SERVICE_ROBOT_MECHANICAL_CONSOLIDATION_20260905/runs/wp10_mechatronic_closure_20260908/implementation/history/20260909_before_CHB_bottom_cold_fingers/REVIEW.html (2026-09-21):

WP10 · 同一活动候选 · 2026-09-09

# 底部散热结构与24件原生SolidWorks安装组件已生成

设计增量可查看，整机闭环仍开放。
任务吸能、动态、完整热路径和整星装配仍需完成；没有制造、通电或飞行放行。

201位号 · 11页原理图 · 435项原生检查 · 104项制动检查

## 当前底部安装交付

底板、甲板、四角码、18紧固件，共24实例/24实体；9个原生SLDPRT与SLDASM已保存并独立冷读。三个状态各531对改件邻域零穿透。整星884原生总装、CHB到底板热连接及机电全功能闭环仍开放。

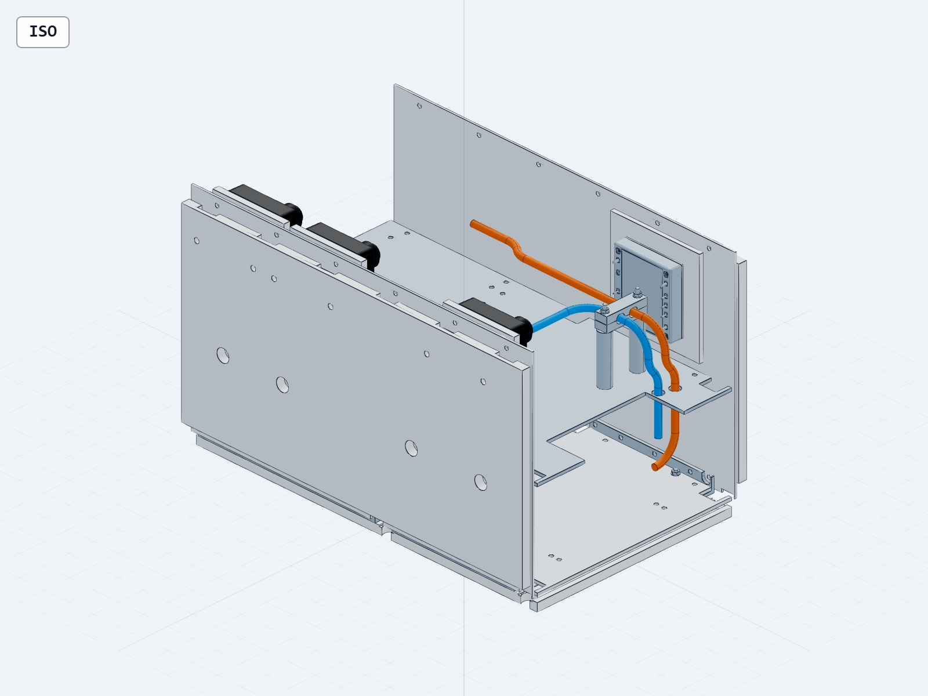
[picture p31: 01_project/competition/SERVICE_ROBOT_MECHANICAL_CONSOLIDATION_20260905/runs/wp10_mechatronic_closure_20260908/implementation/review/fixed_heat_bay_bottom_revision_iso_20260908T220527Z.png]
当前整舱改件


## 本轮实际整舱改件

两固定外壁、四组器件/TIM接触、14件夹具移位、新孔及R21线束。三状态各531对改件邻域接口零穿透；整星运动、工具、公差与原生总装仍需核验。单侧85%效率热场景失败，完整设计保持开放。

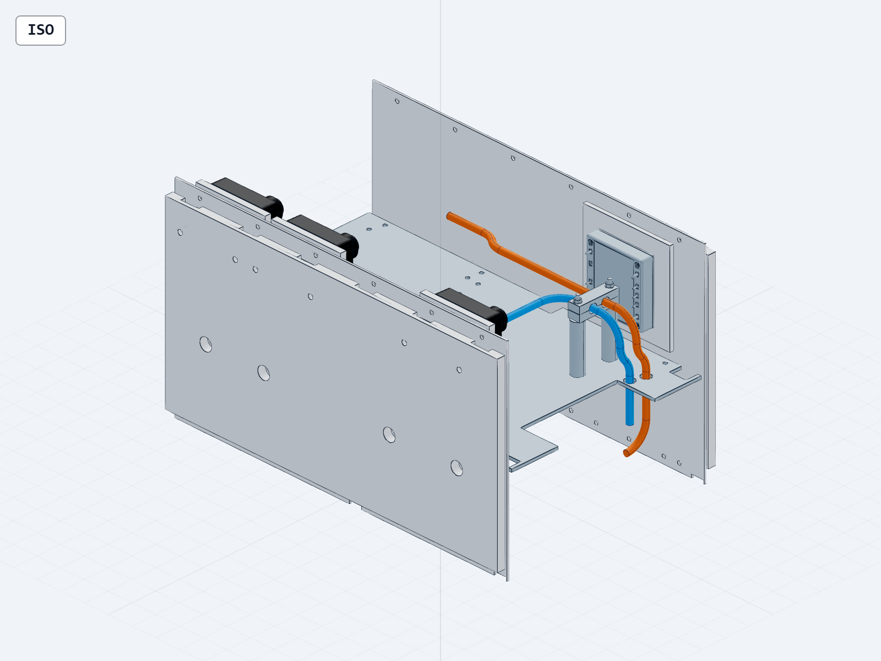
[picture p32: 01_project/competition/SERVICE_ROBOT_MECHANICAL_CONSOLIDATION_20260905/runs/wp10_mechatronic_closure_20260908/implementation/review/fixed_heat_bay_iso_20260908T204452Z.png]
本轮固定热路径与舱板线束实体快照


## 本轮启动与停止预算

17个器件已接入输入侧自动启动；修复带电电容与PGD下游断线反例。完整故障网覆盖11个开漏输出。物理启动及停止动态尚未验证。

## 实际电气源

负载侧自供电制动与三温感停止链已接入；动态、真实回生能量和PCB仍待完成。

## 前版局部组件研究

厂家LPS300实体、三片Q2500与承载板；当前安装位置以本轮固定散热壁为准；温感、紧固件及原生整星集成仍开放。

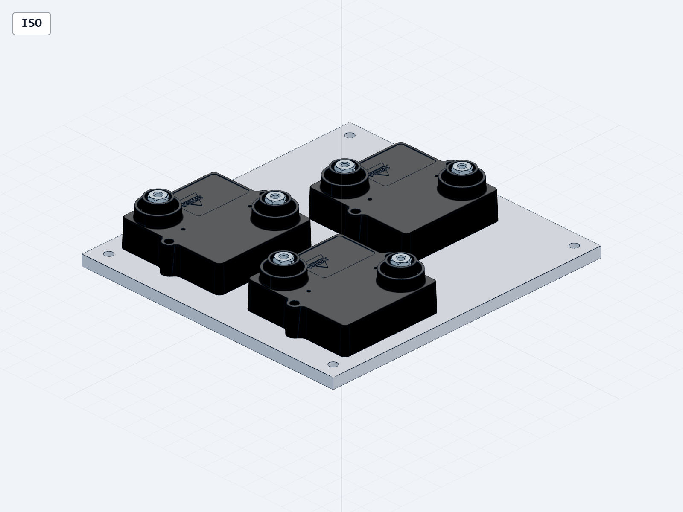
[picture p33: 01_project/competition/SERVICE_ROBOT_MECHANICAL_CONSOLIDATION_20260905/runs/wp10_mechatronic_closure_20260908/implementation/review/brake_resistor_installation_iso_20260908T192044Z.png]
实际三电阻与承载板装配快照


## 已有转换器接口

真实TSP1600S接口保持；873组件封存父本原字节保持。

## 交付状态

原37行保持13有界子项完成、19内部开放、4外部未绑定、1物理未执行。整机机电详细设计仍开放。

原生电气导出节选

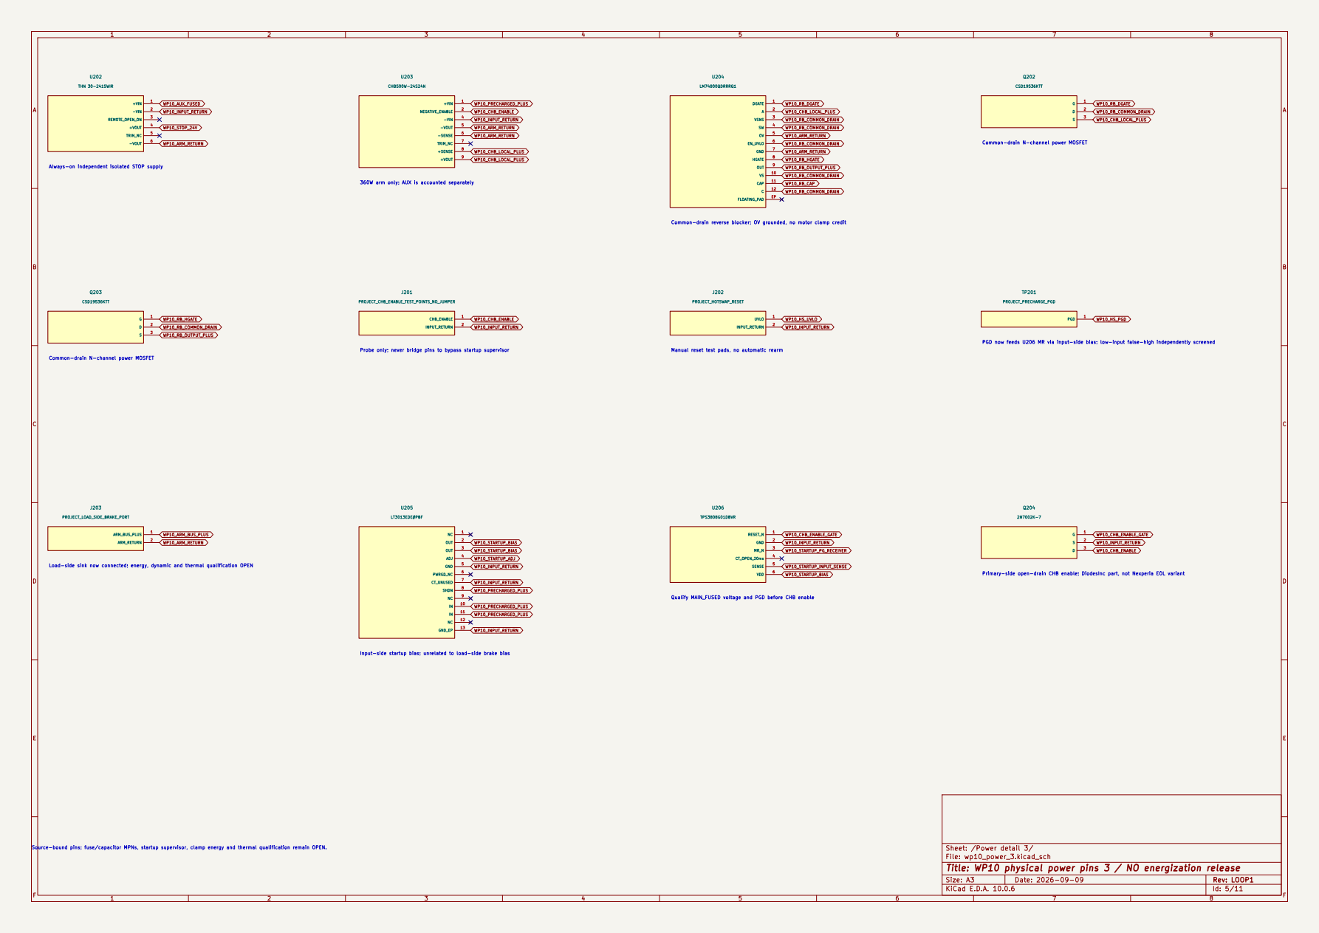
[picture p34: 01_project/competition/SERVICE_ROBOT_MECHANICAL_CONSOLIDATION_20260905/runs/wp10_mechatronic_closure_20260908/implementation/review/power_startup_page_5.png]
当前实际输入侧启动原生页


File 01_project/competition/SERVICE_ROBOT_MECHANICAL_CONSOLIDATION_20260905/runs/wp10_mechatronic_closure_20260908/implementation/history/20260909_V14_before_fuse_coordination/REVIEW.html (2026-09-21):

航天服务星 · B601 DM · 同一 WP10 候选

# C203 输入电容机械安装候选

本轮实际改件已完成几何与接口核对。整机机电设计仍开放；未制造、未接电，未获得飞行放行。

965当前三态源实例

29新增安装实例

79 × 3局部精确实体对

7仍开放的ERC问题

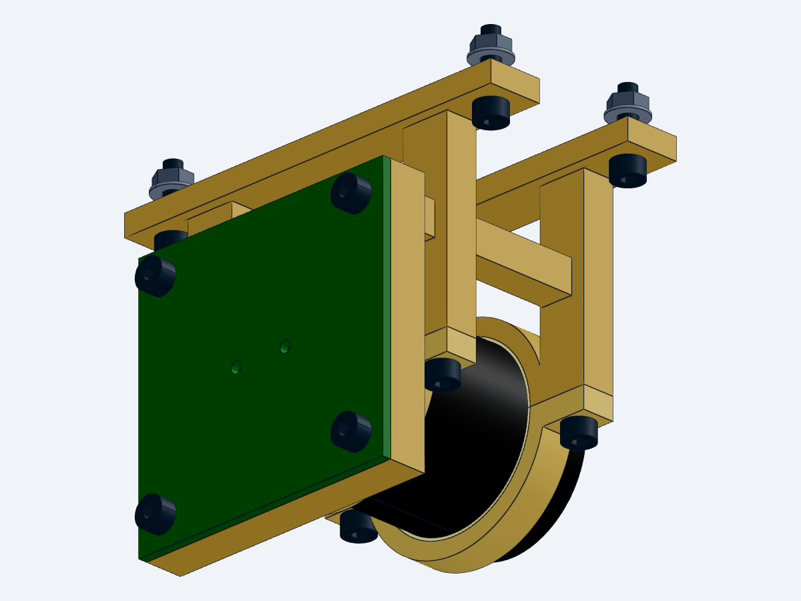
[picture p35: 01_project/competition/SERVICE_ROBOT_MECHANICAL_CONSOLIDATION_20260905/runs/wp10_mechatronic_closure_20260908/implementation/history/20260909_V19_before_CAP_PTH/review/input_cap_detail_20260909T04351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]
C203横卧电容、端子板和保持架，甲板省略
打开安装架三维模型 (http://127.0.0.1:3245/F:/China%20Graduate%20Future%20Flight%20Vehicle%20Innovation%20Competition/01_project/competition/SERVICE_ROBOT_MECHANICAL_CONSOLIDATION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)打开局部装配三维模型 (http://127.0.0.1:3245/F:/China%20Graduate%20Future%20Flight%20Vehicle%20Innovation%20Competition/01_project/competition/SERVICE_ROBOT_MECHANICAL_CONSOLIDATION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) 

四个甲板孔已外移至y±32.5；两个板孔已改为连接筋合并后钻孔。三态各35个必需接触及泄压/工具末段检查通过。PCB铜箔、CHB端接、夹紧力与热环境仍需完成。

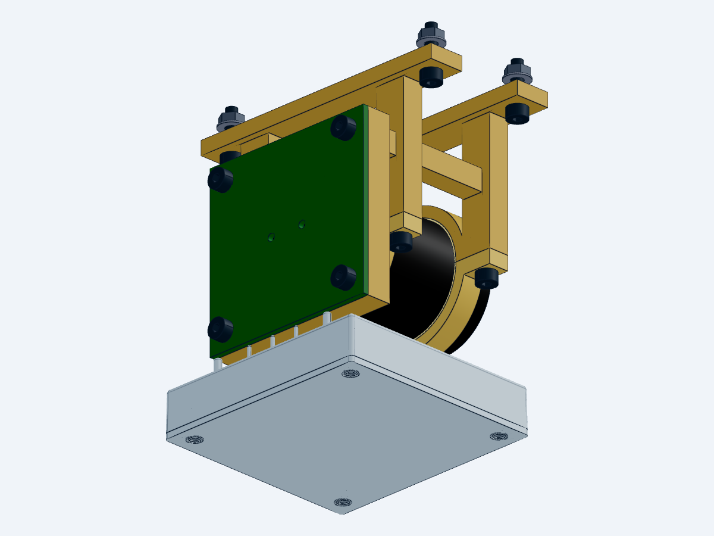
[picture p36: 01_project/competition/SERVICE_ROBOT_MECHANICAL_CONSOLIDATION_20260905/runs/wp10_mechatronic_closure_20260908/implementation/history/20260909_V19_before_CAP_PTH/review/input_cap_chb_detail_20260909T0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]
37件局部设备舱源模型


上图仅显示29件安装架与CHB，其余7组邻件为观察而隐藏，仍在三维文件和精确检查中。新增件和修改甲板共30件完成含自交验证；既有背景件全量自交触发内存保护，保留为未完成。

电气保留201位号和11页；ERC修复消除的是1个封装库warning，其余7个error保留。旧热模型与38件SolidWorks热核不取得本次965实例的整机信用。

29件安装架 STEP37件局部总装 STEP965实例表安装BOM原生电路PDF精确验证只读审阅CAD/ECAD接口37行闭环矩阵当前机器裁决完整说明整合ZIP

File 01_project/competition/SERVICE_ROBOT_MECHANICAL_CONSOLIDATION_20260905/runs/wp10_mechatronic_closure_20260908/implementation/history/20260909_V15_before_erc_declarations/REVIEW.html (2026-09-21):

航天服务星 · B601 DM · 同一 WP10 候选

# V15 输入保护选件与机电接口集成

F201封装、F202具体型号和冷阻已进入原理图/BOM/计算；整机设计与故障保护仍开放。未制造、未接电，未获得飞行放行。

201 / 11电气位号 / 页

192共享电源场景

4032细分热账行

7仍开放的ERC错误

F201焊盘中心距9.35mm，12.60mm为外缘总跨距。F202选定MDA-V-6-R，典型冷阻18mΩ在辅助支路计入一次。保护动作、输入浪涌、热态阻值和实际布板/端接仍需完成；两个热CSV不能相加。

原生电路PDF当前电气BOM输入保护设计说明F201实际封装SVG保险协调与反例输入无源只读复核C203精确检查CAD/ECAD接口安装BOM29件安装架STEP37件局部STEP965实例源表37行闭环矩阵当前机器裁决完整说明整合ZIP

## 当前机械安装关系

965实例源表保持；本轮重验了C203与新网表的绑定，三态各79实体对/35必需接触及空间、工具末段检查通过。实际保持力、热环境、近端线路和整机装配仍开放。

查看29件安装架 (http://127.0.0.1:3245/F:/China%20Graduate%20Future%20Flight%20Vehicle%20Innovation%20Competition/01_project/competition/SERVICE_ROBOT_MECHANICAL_CONSOLIDATION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)查看37件局部三维 (http://127.0.0.1:3245/F:/China%20Graduate%20Future%20Flight%20Vehicle%20Innovation%20Competition/01_project/competition/SERVICE_ROBOT_MECHANICAL_CONSOLIDATION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) C203安装架，甲板省略 C203与CHB局部安装关系

第二张图为观察隐藏7组邻件，源模型与检查仍包含它们。30个新增/修改实体有含自交验证；旧背景件全量自交受内存保护中止。原37行状态仍为13个限定子项完成、19内部开放、4外部接口未绑定、1实物未执行。

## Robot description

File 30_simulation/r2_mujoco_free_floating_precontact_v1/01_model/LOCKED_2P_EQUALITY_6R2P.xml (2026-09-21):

<?xml version='1.0' encoding='utf-8'?>
<mujoco model="r2_locked_2p_equality_6r2p">
  <compiler angle="radian" autolimits="false" balanceinertia="false" boundmass="0" boundinertia="0" discardvisual="false" fusestatic="false" inertiafromgeom="false" />
  <option timestep="0.00025000000000000001" gravity="0 0 0" integrator="RK4" jacobian="dense" cone="elliptic">
    <flag contact="disable" />
  </option>
  <default>
    <joint damping="0" frictionloss="0" armature="0" stiffness="0" />
    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
  </default>
  <worldbody>
    <body name="spacecraft_bus">
      <freejoint name="servicer_free" align="false" />
      <inertial pos="-0.0119840711789168 -6.6595220797882536e-07 0.0007839544760700856" mass="17.26823279235072" quat="0.70710757303405303 0.70709419805908458 -0.0028945618369108214 0.0028804063678390837" diaginertia="0.12234548002716673 0.23074178061430084 0.23221057680550161" />
      <body name="bus_primary_structure_candidate_v1" pos="0 0 0" quat="1 0 0 0">
        <inertial pos="0.031218994211701909 1.905526877979096e-06 2.344297084187758e-05" mass="6.0349806076492811" quat="0.99999997724855116 -2.2429501335127842e-05 0.0002108749256763526 2.3056026987283696e-05" diaginertia="0.071229696771779566 0.10797810852551407 0.10799032761402258" />
        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
      </body>
      <body name="D_BUS_MATE_PHYSICAL" pos="0.18525 0 0" quat="0.70710678118654746 0 0.70710678118654757 0">
        <body name="D_BUS_M6_PATTERN" pos="8.6366069999999998e-05 1.5994150999999999e-05 0" quat="0.97629598067690637 0 0 0.21643973321485527">
          <body name="load_bridge_candidate" pos="0 0 0" quat="1 0 0 0">
            <inertial pos="-1.2725692226922191e-10 -1.072691633523576e-10 0.0053750000000000742" mass="0.70219545800000005" quat="0.97367705150808936 -1.3561112753724747e-19 -2.9676140630944835e-20 -0.22793200601607824" diaginertia="0.0015679069727329111 0.0015679069727329205 0.0031222893683617043" />
            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
            <body name="m3r_lumped_link" pos="4.2351647362715017e-21 0 0.022749999999999989" quat="1 0 0 0">
              <inertial pos="-1.2725692881822051e-10 -1.072691664294674e-10 -0.0046120551126256903" mass="0.76190000000000002" quat="1 0 0 0" diaginertia="0.001808962466764922 0.001808962466764922 0.0035940027551963792" />
              <body name="base_link" pos="-8.5033656693770215e-05 2.2004275556030842e-05 0" quat="1 0 0 0">
                <inertial pos="-7.8490000000000006e-06 -1.1531e-06 0.029840999999999999" mass="0.83660000000000001" quat="0.99999999998050726 0 0 -6.2438342123751554e-06" diaginertia="0.0013303999998751234 0.0021311900001248765 0.0027587699999999998" />
                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
                <body name="link1" pos="-8.4159999999999994e-05 0 0.084650000000000003" quat="1 0 0 0">
                  <joint name="joint1" type="hinge" axis="0 0 1" pos="0 0 0" limited="true" range="-2.7999999999999998 2.7999999999999998" />
                  <inertial pos="0.00011361455295162701 -0.00061631952705132299 0.0236476372671394" mass="0.1613" quat="0.31977478086382516 0.63066955652187029 0.63066955652187018 0.31977478086382544" diaginertia="0.00015464000000000002 0.00021341290537689304 0.000272817094623107" />
                  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
                  <body name="link2" pos="0.020084000000000001 0.031625 0.055550000000000002" quat="0.70710548251123639 -0.70710807985947366 0 0">
                    <joint name="joint2" type="hinge" axis="0 0 -1" pos="0 0 0" limited="true" range="-3.1400000000000001 0" />
                    <inertial pos="-0.13225622308887999 -0.0030617036386309002 -0.030830696703020501" mass="1.3266" quat="0.99999676527968562 -0.0025189343337732777 0.0003521859902678853 1.910538619037344e-05" diaginertia="0.00073373398932560438 0.012559863568678083 0.01281388244199631" />
                    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
                    <body name="link3" pos="-0.26400000000000001 0 0" quat="1 0 0 0">
                      <joint name="joint3" type="hinge" axis="0 0 1" pos="0 0 0" limited="true" range="-3.1400000000000001 0" />
                      <inertial pos="0.121040035791843 -0.053621107662794897 -0.0310137854608077" mass="0.83530000000000004" quat="0.99998889024404591 -0.00099130490408275694 -0.0035441352141068884 0.0029454725686692816" diaginertia="0.00046756443869106195 0.0063271532296793366 0.0064825123316296024" />
                      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
                      <body name="link4" pos="0.24260000000000001 -0.053999999999999999 -0.0016249999999999999" quat="1 0 0 0">
                        <joint name="joint4" type="hinge" axis="0 0 1" pos="0 0 0" limited="true" range="-1.8700000000000001 1.5700000000000001" />
                        <inertial pos="0.060820095629313599 -0.051171190661312198 -0.030299458623927002" mass="0.52000000000000002" quat="0.69689489084473655 0.67070156753387877 -0.17956493955902669 -0.17959217940451602" diaginertia="0.0003232105530213145 0.00066716476121395226 0.00088948468576473293" />
                        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
                        <body name="link5" pos="0.078308000000000003 -0.037499999999999999 -0.029999999999999999" quat="0.70710548251123639 -0.70710807985947366 0 0">
                          <joint name="joint5" type="hinge" axis="0 0 1" pos="0 0 0" limited="true" range="-1.5700000000000001 1.5700000000000001" />
                          <inertial pos="-0.0050280205898251698 1.7386620669236401e-06 0.038623323632675503" mass="0.38300000000000001" quat="0.64607762444149208 -0.58316489420647422 -0.36748548757922656 -0.32780607953460572" diaginertia="0.00015733463979509366 0.00021223667927982521 0.00021742868092508127" />
                          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
                          <body name="link6" pos="0.023692000000000001 0 0.040000000000000001" quat="0.70710548251123639 -0 0.70710807985947366 -0">
                            <joint name="joint6" type="hinge" axis="0 0 1" pos="0 0 0" limited="true" range="-3.1400000000000001 3.1400000000000001" />
                            <inertial pos="3.7641872712712602e-06 -0.00010090881994667701 0.0253308606425965" mass="0.36630000000000001" quat="0.70710678118654757 0 -0.70710678118654746 0" diaginertia="0.00013966 0.00015553999999999999 0.00015553999999999999" />
                            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
                            <body name="gripper_link" pos="0 0 0.15970999999999999" quat="0.70710548251123639 0 -0.70710807985947366 0">
                              <inertial pos="-0.11400456131826001 7.3080932858954104e-05 -8.0982546862839997e-08" mass="0.181800159145243" quat="0.5003738811260201 0.50042401477367626 0.49958642528150288 0.49961504000493057" diaginertia="5.8508142684152297e-05 0.00020521353674824832 0.00023238627147926413" />
                              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
                              <body name="gripper_left" pos="-0.042091000000000003 2.7531000000000001e-05 -1.3030999999999999e-05" quat="0.70710548251123639 0 0 -0.70710807985947366">
                                <joint name="gripper_joint1" type="slide" axis="1 0 0" pos="0 0 0" limited="true" range="0 0.071499999999999994" />
                                <inertial pos="0.0093715460594514192 -0.018351440900627899 -0.0021305081322361701" mass="0.042327895241615801" quat="0.92219166680733022 -0.070162254522603273 -0.010048447640092507 0.38018260929643793" diaginertia="8.5548862838440899e-06 1.0839342746622605e-05 1.1377372612026584e-05" />
                              </body>
                              <body name="gripper_right" pos="-0.042091000000000003 -2.7531000000000001e-05 1.3030999999999999e-05" quat="0.70710548251123639 0 0 0.70710807985947366">
                                <joint name="gripper_joint2" type="slide" axis="1 0 0" pos="0 0 0" limited="true" range="0 0.071499999999999994" />
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

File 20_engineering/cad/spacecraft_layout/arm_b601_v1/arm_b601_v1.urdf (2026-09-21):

<?xml version='1.0' encoding='utf-8'?>
<robot name="arm_b601_v1">
  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<link name="base_link">
    <inertial>
      <origin xyz="-7.849E-06 -1.1531E-06 0.029841" rpy="0 0 0" />
      <mass value="0.83660000" />
      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
    </inertial>
    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
  </link>
  <link name="link1">
    <inertial>
      <origin xyz="0.000113614552951627 -0.000616319527051323 0.0236476372671394" rpy="0 0 0" />
      <mass value="0.16130000" />
      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
    </inertial>
    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
  </link>
  <joint name="joint1" type="revolute">
    <origin xyz="-8.416E-05 0 0.08465" rpy="0 0 0" />
    <parent link="base_link" />
    <child link="link1" />
    <axis xyz="0 0 1" />
    <limit lower="-2.8" upper="2.8" effort="27" velocity="50" />
  </joint>
  <link name="link2">
    <inertial>
      <origin xyz="-0.13225622308888 -0.0030617036386309 -0.0308306967030205" rpy="0 0 0" />
      <mass value="1.32660000" />
      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
    </inertial>
    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
  </link>
  <joint name="joint2" type="revolute">
    <origin xyz="0.020084 0.031625 0.05555" rpy="-1.5708 0 0" />
    <parent link="link1" />
    <child link="link2" />
    <axis xyz="0 0 -1" />
    <limit lower="-3.14" upper="0" effort="27" velocity="50" />
  </joint>
  <link name="link3">
    <inertial>
      <origin xyz="0.121040035791843 -0.0536211076627949 -0.0310137854608077" rpy="0 0 0" />
      <mass value="0.83530000" />
      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
    </inertial>
    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
  </link>
  <joint name="joint3" type="revolute">
    <origin xyz="-0.264 0 0" rpy="0 0 0" />
    <parent link="link2" />
    <child link="link3" />
    <axis xyz="0 0 1" />
    <limit lower="-3.14" upper="0" effort="27" velocity="50" />
  </joint>
  <link name="link4">
    <inertial>
      <origin xyz="0.0608200956293136 -0.0511711906613122 -0.030299458623927" rpy="0 0 0" />
      <mass value="0.52000000" />
      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
    </inertial>
    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
  </link>
  <joint name="joint4" type="revolute">
    <origin xyz="0.2426 -0.054 -0.001625" rpy="0 0 0" />
    <parent link="link3" />
    <child link="link4" />
    <axis xyz="0 0 1" />
    <limit lower="-1.87" upper="1.57" effort="7" velocity="200" />
  </joint>
  <link name="link5">
    <inertial>
      <origin xyz="-0.00502802058982517 1.73866206692364E-06 0.0386233236326755" rpy="0 0 0" />
      <mass value="0.38300000" />
      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
    </inertial>
    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
  </link>
  <joint name="joint5" type="revolute">
    <origin xyz="0.078308 -0.0375 -0.03" rpy="-1.5708 0 0" />
    <parent link="link4" />
    <child link="link5" />
    <axis xyz="0 0 1" />
    <limit lower="-1.57" upper="1.57" effort="7" velocity="200" />
  </joint>
  <link name="link6">
    <inertial>
      <origin xyz="3.76418727127126E-06 -0.000100908819946677 0.0253308606425965" rpy="0 0 0" />
      <mass value="0.36630000" />
      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
    </inertial>
    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
  </link>
  <joint name="joint6" type="revolute">
    <origin xyz="0.023692 0 0.04" rpy="0 1.5708 0" />
    <parent link="link5" />
    <child link="link6" />
    <axis xyz="0 0 1" />
    <limit lower="-3.14" upper="3.14" effort="7" velocity="200" />
  </joint>
  <link name="gripper_link">
    <inertial>
      <origin xyz="-0.11400456131826 7.30809328589541E-05 -8.098254686284E-08" rpy="0 0 0" />
      <mass value="0.181800159145243" />
      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
    </inertial>
    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
  </link>
  <joint name="gripper_joint" type="fixed">
    <origin xyz="0 0 0.15971" rpy="0 -1.5708 0" />
    <parent link="link6" />
    <child link="gripper_link" />
    <axis xyz="0 0 0" />
  </joint>
  <link name="gripper_left">
    <inertial>
      <origin xyz="0.00937154605945142 -0.0183514409006279 -0.00213050813223617" rpy="0 0 0" />
      <mass value="0.0423278952416158" />
      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
    </inertial>
    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
  </link>
  <joint name="gripper_joint1" type="prismatic">
    <origin xyz="-0.042091 2.7531E-05 -1.3031E-05" rpy="0 0 -1.5708" />
    <parent link="gripper_link" />
    <child link="gripper_left" />
    <axis xyz="1 0 0" />
    <limit lower="0" upper="0.0715" effort="100" velocity="15" />
  </joint>
  <link name="gripper_right">
    <inertial>
      <origin xyz="0.00937154599936671 0.0183514410059713 0.00213050822993754" rpy="0 0 0" />
      <mass value="0.0423278949561274" />
      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
    </inertial>
    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
  </link>
  <joint name="gripper_joint2" type="prismatic">
    <origin xyz="-0.042091 -2.7531E-05 1.3031E-05" rpy="0 0 1.5708" />
    <parent link="gripper_link" />
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

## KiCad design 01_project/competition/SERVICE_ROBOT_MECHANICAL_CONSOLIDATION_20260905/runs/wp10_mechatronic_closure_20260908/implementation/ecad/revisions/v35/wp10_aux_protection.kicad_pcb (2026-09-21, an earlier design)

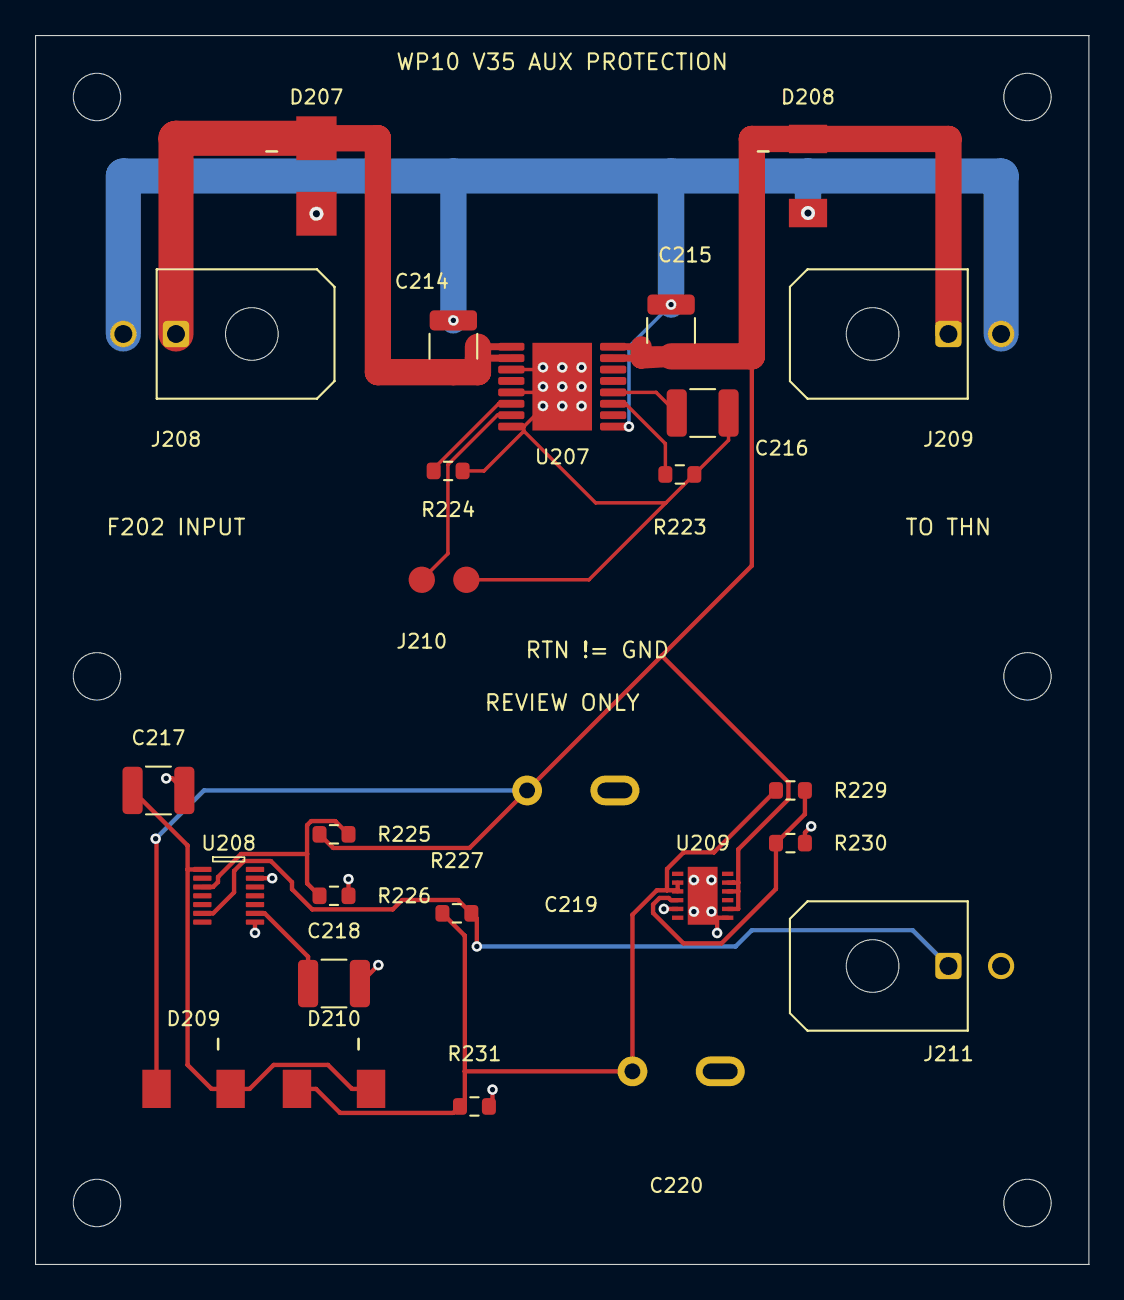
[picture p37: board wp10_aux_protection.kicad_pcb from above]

Board: 2 copper layers, 60.0 x 70.0 mm, 32 parts (0 on the bottom side), 14 nets.

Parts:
C214, C215, C216, C217, C218: 100nF 100V C0G; C_1210_3225Metric
C219: MKS2D041501M00JSSD; MKS2_D041501M00_P5_Slot2
C220: MKS2D044701O00JSSD; MKS2_D044701O00_P5_Slot2
D207: SMBJ30CA-13-F; SMBJ30A_A1K2
D208, D209, D210: STPS3H100U; STPS3H100U_K1A2
J208: 43045-0200 IN; Molex_Micro-Fit_3.0_43045-0200_2x01_P3.00mm_Horizontal
J209: 43045-0200 TO_THN; Molex_Micro-Fit_3.0_43045-0200_2x01_P3.00mm_Horizontal
J210: LOCAL_RESET_TEST_PADS; ResetTestPads
J211: 430450200; Molex_Micro-Fit_3.0_43045-0200_2x01_P3.00mm_Horizontal
MH34_1, MH34_2, MH34_3, MH34_4: M2.5 NPTH 2.7mm; MountingHole_2.7mm_M2.5
MH35_1, MH35_2: MountingHole_2.7mm_M2.5
R223: 5.36k; R_0603_1608Metric
R224: 402k; R_0603_1608Metric
R225: 200k; R_0603_1608Metric
R226, R230: 10k; R_0603_1608Metric
R227: 2.00k; R_0603_1608Metric
R229: 38.3k; R_0603_1608Metric
R231: 1.80k; R_0603_1608Metric
U207: TPS26600PWPR; TPS26600_PWP16_EP17
U208: TPS3760A015DYYR; TPS3760_DYY14
U209: LT3013EDE#PBF; LT3013_DE12_EP13_3x4_Pin1LeftTop

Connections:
WP10_AUX_CTR: C218.1, U208.9
WP10_AUX_DVDT: C216.1, U207.12
WP10_AUX_FUSED: C214.1, D207.2, J208.1, U207.1, U207.2
WP10_AUX_ILIM: R223.1, U207.11
WP10_AUX_LIMITED: C215.1, C219.1, D208.1, D209.2, J209.1, R225.1, U207.15, U207.16, U209.8, U209.10, U209.11
WP10_AUX_MODE: R224.1, U207.6
WP10_AUX_PROTECT_RTN: C216.2, J210.2, R223.2, R224.2, U207.3, U207.5, U207.8, U207.17
WP10_AUX_REMOTE_ADJ: R229.2, R230.1, U209.4
WP10_AUX_REMOTE_BIAS: C220.1, D210.2, R227.1, R229.1, R231.1, U209.2, U209.3
WP10_AUX_RESET: J210.1, U207.7
WP10_AUX_SEQ_VDD: C217.1, D209.1, D210.1, U208.1
WP10_AUX_UV_SENSE: R225.2, R226.1, U208.3
WP10_INPUT_RETURN: C214.2, C215.2, C217.2, C218.2, C219.2, C220.2, D207.1, D208.2, J208.2, J209.2, J211.2, R226.2, R230.2, R231.2, U207.9, U208.8, U208.13, U209.5, U209.7, U209.13
WP10_THN_REMOTE: J211.1, R227.2, U208.6

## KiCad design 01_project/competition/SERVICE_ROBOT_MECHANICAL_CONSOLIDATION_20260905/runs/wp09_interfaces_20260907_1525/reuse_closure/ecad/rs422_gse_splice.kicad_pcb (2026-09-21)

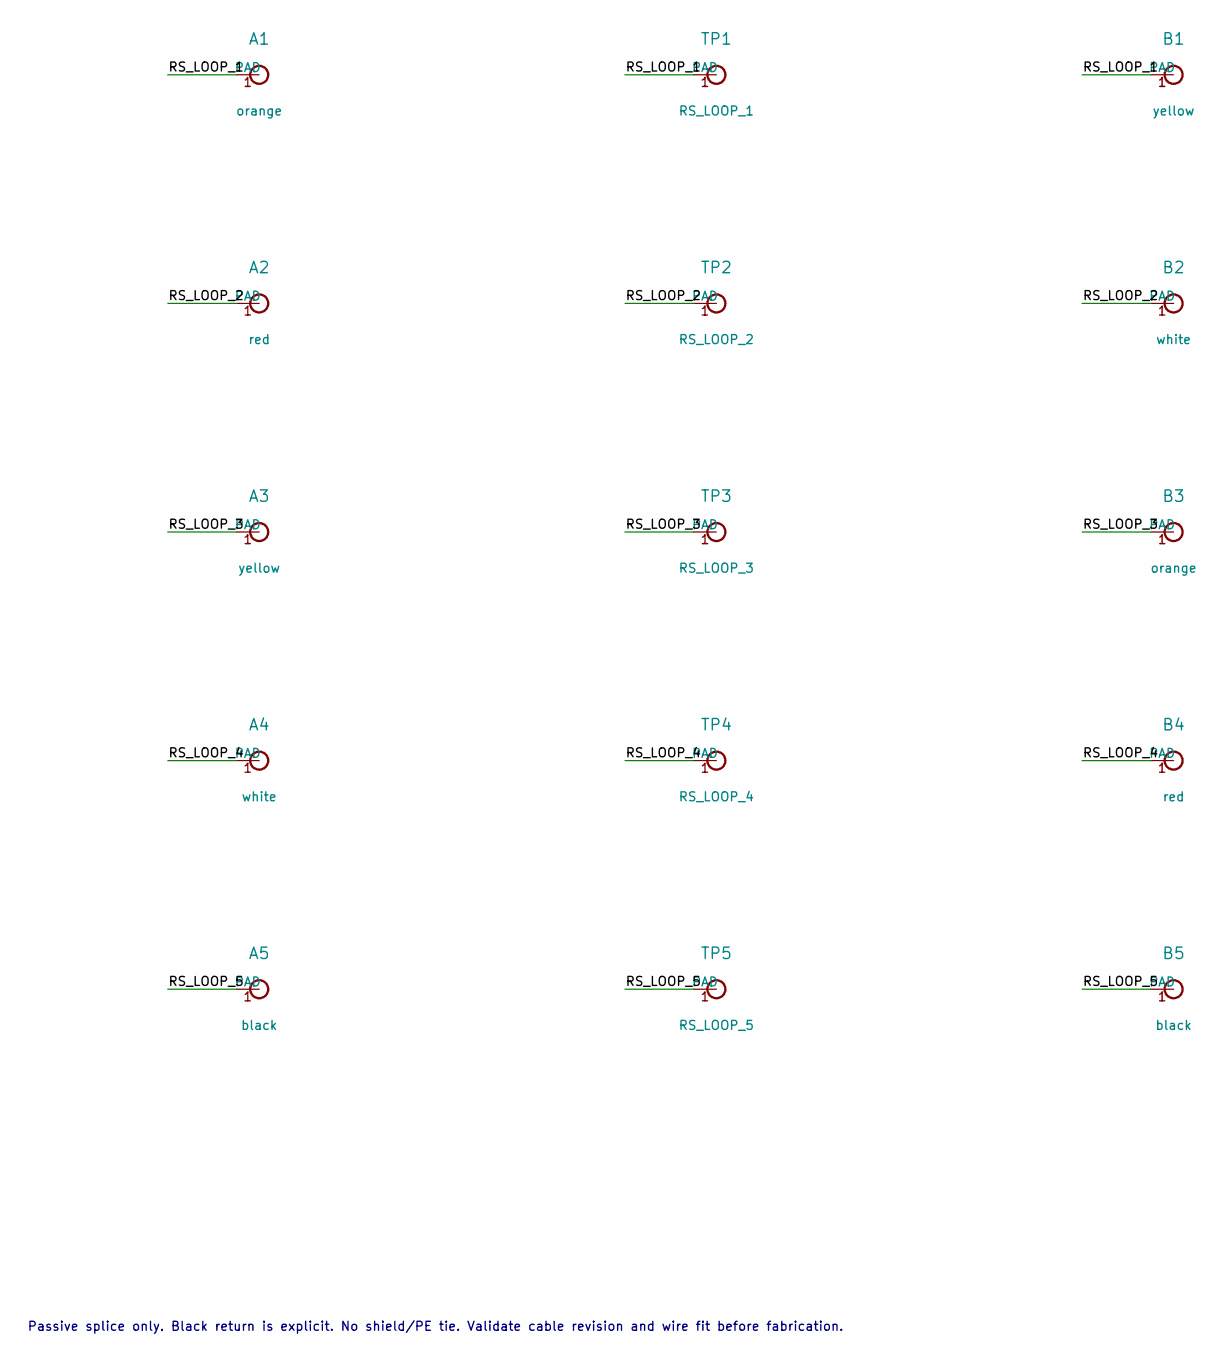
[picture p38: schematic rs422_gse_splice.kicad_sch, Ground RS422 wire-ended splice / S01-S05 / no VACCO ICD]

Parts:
A1: orange; WirePad_GSE
A2: red; WirePad_GSE
A3: yellow; WirePad_GSE
A4: white; WirePad_GSE
A5: black; WirePad_GSE
B1: yellow; WirePad_GSE
B2: white; WirePad_GSE
B3: orange; WirePad_GSE
B4: red; WirePad_GSE
B5: black; WirePad_GSE
TP1: RS_LOOP_1; TestPoint-MinTH
TP2: RS_LOOP_2; TestPoint-MinTH
TP3: RS_LOOP_3; TestPoint-MinTH
TP4: RS_LOOP_4; TestPoint-MinTH
TP5: RS_LOOP_5; TestPoint-MinTH

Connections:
/RS_LOOP_1: A1.1, B1.1, TP1.1
/RS_LOOP_2: A2.1, B2.1, TP2.1
/RS_LOOP_3: A3.1, B3.1, TP3.1
/RS_LOOP_4: A4.1, B4.1, TP4.1
/RS_LOOP_5: A5.1, B5.1, TP5.1

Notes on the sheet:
Passive splice only. Black return is explicit. No shield/PE tie. Validate cable revision and wire fit before fabrication.

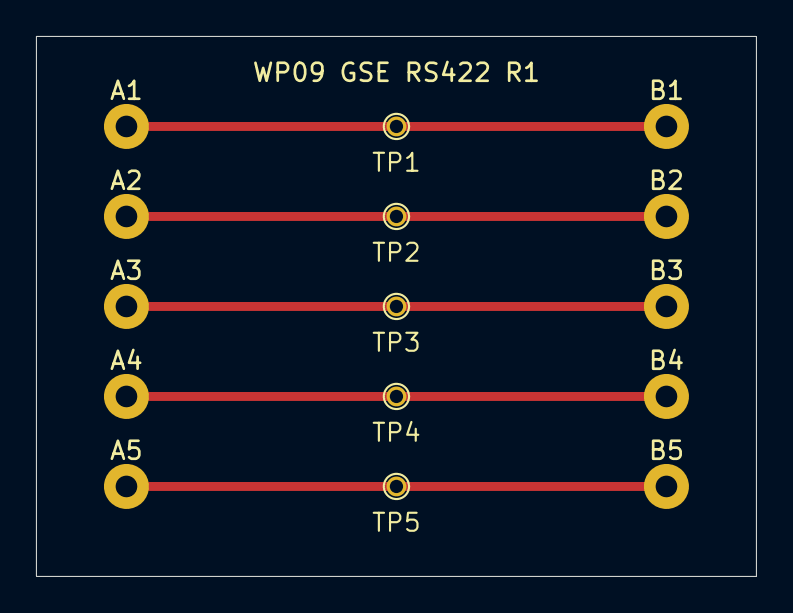
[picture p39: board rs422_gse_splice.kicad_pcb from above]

Board: 2 copper layers, 40.0 x 30.0 mm, 15 parts (0 on the bottom side), 5 nets.

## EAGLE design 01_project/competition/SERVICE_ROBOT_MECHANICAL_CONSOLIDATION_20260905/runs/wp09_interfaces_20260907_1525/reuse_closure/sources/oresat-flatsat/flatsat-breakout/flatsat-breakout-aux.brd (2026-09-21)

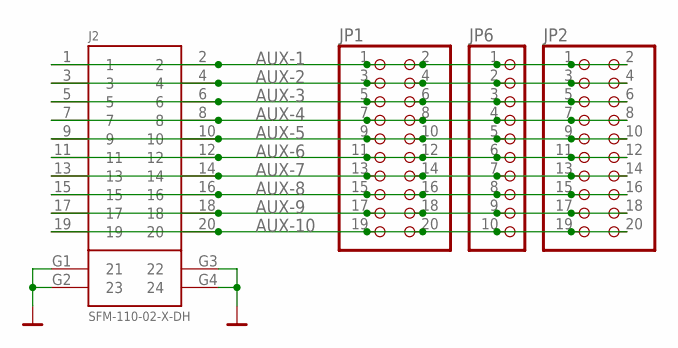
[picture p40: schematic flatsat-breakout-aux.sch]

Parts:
J2: SFM-110-02-X-DH
JP1, JP2: PINHD-2X10; 2X10
JP6: PINHD-1X10; 1X10

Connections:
AUX-1: J2.1, J2.2, JP1.1, JP1.2, JP2.1, JP2.2, JP6.1
AUX-2: J2.3, J2.4, JP1.3, JP1.4, JP2.3, JP2.4, JP6.2
AUX-3: J2.5, J2.6, JP1.5, JP1.6, JP2.5, JP2.6, JP6.3
AUX-4: J2.7, J2.8, JP1.7, JP1.8, JP2.7, JP2.8, JP6.4
AUX-5: J2.9, J2.10, JP1.9, JP1.10, JP2.9, JP2.10, JP6.5
AUX-6: J2.11, J2.12, JP1.11, JP1.12, JP2.11, JP2.12, JP6.6
AUX-7: J2.13, J2.14, JP1.13, JP1.14, JP2.13, JP2.14, JP6.7
AUX-8: J2.15, J2.16, JP1.15, JP1.16, JP2.15, JP2.16, JP6.8
AUX-9: J2.17, J2.18, JP1.17, JP1.18, JP2.17, JP2.18, JP6.9
AUX-10: J2.19, J2.20, JP1.19, JP1.20, JP2.19, JP2.20, JP6.10
GND: J2.G1 (21), J2.G2 (23), J2.G3 (22), J2.G4 (24)

Board: 2 copper layers, 9 parts (0 on the bottom side), 11 nets, no tracks yet.

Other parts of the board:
H1, H2, H3, H4, H5: STAND-OFFTIGHT; STAND-OFF-TIGHT

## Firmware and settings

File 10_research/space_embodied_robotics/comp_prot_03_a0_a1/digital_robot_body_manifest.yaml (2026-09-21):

schema_version: comp-prot-03-a1-digital-body-manifest-v1
manifest_id: digital_space_robot_body_v1
phase: COMP-PROT-03-A0_A1
created_on: "2026-07-23"
status: DIGITAL_MODEL_ARCHITECTURE_ONLY

manifest_meta:
  baseline_git_head: b75352c1c226c0f3e9a4bc9c469b766e06f41616
  hash_contract:
    algorithm: SHA-256
    mode: RAW_BYTES
    normalized_content_hash_accepted_as_substitute: false
  package_form: COMPONENT_PACKAGE_NOT_INTEGRATED_DIGITAL_BODY
  current_model_conformance: BLOCKED_BY_EVIDENCE
  note: this_manifest_is_a_design_and_evidence_ledger_not_a_runtime_configuration

authority:
  scientific_gate: false
  runtime_configuration: false
  implementation_authorized: false
  candidate_model_accepted: false
  cad_generation_authorized: false
  urdf_generation_authorized: false
  external_asset_download_authorized: false
  simulation_authorized: false
  controller_or_safe_authorized: false
  cannot_override:
    - human_scope_authorization
    - original_gate_json
    - frozen_geometry_config
    - accepted_urdf
    - mass_inertia_budget
    - license_gate

baseline:
  name: servicer_12U_v0_plus_arm_b601_v1_plus_target_library_v0
  selection_reason: minimum_evidence_drift_from_existing_12U_and_reBot_hardware_mapping
  rejected_parallel_variants:
    - id: generic_7dof_arm
      status: REJECTED_VARIANT
      reason: conflicts_with_B601_6R_hardware_baseline
    - id: alternate_12_to_15kg_servicer
      status: REJECTED_VARIANT
      reason: conflicts_with_existing_24kg_reference_anchor

truth_order:
  - latest_human_scope_authorization
  - original_scientific_gate_and_bound_config
  - geometry_and_frame_ssot
  - accepted_b601_urdf
  - mass_inertia_budget
  - project_object_json_cad_step_stl
  - derived_importer_assets
  - visualization_and_narrative

source_bindings:
  - source_id: arm_geometry_ssot
    path: 20_engineering/config/geometry/arm_b601_v1.yaml
    sha256: c81bd3696ce1ee789574aa3b143ea0057ffc286305a1aa18802829e9f038b188
    role: CANONICAL_PROJECT_SOURCE
  - source_id: frame_tree_ssot
    path: 20_engineering/config/geometry/frame_tree_v1.yaml
    sha256: 958bff23bf83434c773854fd0e78da3b09be4a3a213eb81a0741514750b3e55b
    role: CANONICAL_PROJECT_SOURCE
  - source_id: servicer_geometry_ssot
    path: 20_engineering/config/geometry/service_spacecraft_v1.yaml
    sha256: 8dd8f22ff1f893273de2215ea12819e4d41cc0e20b853adc0774052237881432
    role: CANONICAL_PROJECT_SOURCE
  - source_id: flexible_appendage_ssot
    path: 20_engineering/config/geometry/flexible_appendage_v1.yaml
    sha256: 52fa88084c628ce8845e05de0c0a892bca5347b7146c8d1c6b99093927153786
    role: CANONICAL_PROJECT_SOURCE
  - source_id: target_geometry_ssot
    path: 20_engineering/config/geometry/target_models_v1.yaml
    sha256: 45666d9d37460fd825f0ed7301bf69113016689fdf00a13dff8046358a76ae45
    role: CANONICAL_PROJECT_SOURCE
  - source_id: arm_mount_ssot
    path: 20_engineering/config/geometry/arm_mount_v1.yaml
    sha256: b08a0f28e4c4f458cd79e6e907f06389ba6a4280c0c7db2b91e36f76134c985c
    role: CANONICAL_PROJECT_SOURCE
  - source_id: capture_interface_ssot
    path: 20_engineering/config/geometry/capture_interface_v1.yaml
    sha256: 54dd2ef8ea0ddd682f1617a8788dbff9a61055d4816b5f09e21c34ba86e5ce85
    role: CANONICAL_PROJECT_SOURCE
  - source_id: mass_inertia_budget
    path: 20_engineering/stage1_spacecraft_layout/04_mass_inertia_budget/mass_inertia_budget_v1.csv
    sha256: 073c802527e35c9495188eefd5d8ba51f524d326142cf2ab31e436bad0899392
    role: CANONICAL_PROJECT_SOURCE
  - source_id: coordinate_frame_definition
    path: 20_engineering/stage1_spacecraft_layout/04_mass_inertia_budget/coordinate_frame_definition_v0.md
    sha256: 6afcb4fb6f1cd53580c5a1561788142e17df7c16a1aeec548dbeafef7efabec1
    role: CANONICAL_PROJECT_SOURCE
  - source_id: accepted_b601_urdf
    path: 20_engineering/cad/spacecraft_layout/arm_b601_v1/arm_b601_v1.urdf
    sha256: 1bc2b7483cd8025d08ba6eadfd9e1f3b0477121714e7cf4ddc1794d9e471c164
    role: ACCEPTED_DERIVED_SOURCE
  - source_id: external_source_manifest
    path: 20_engineering/stage1_spacecraft_layout/00_source_manifest/source_manifest.md
    sha256: cc9ed1110e6a27106f0054356bc7f97bdca5ff70339528cf23ee42029b7834b3
    role: SOURCE_GOVERNANCE
  - source_id: external_license_gate
    path: 20_engineering/stage1_spacecraft_layout/02_open_bus_reference/license_gate_v0.md
    sha256: 0ff7ff8ec2eab183a6ee0a92ae2eb45857027eca053b30edb47e25222dfe77fd
    role: LICENSE_GOVERNANCE
  - source_id: e16_historical_gate
    path: 30_simulation/e16_sync_capture/results/gate_check.json
    sha256: 5538b054805781f7717d316bfc81c9f79cbc6b3b4d6cc9fdc72905d80984cc6f
    role: HISTORICAL_SCIENTIFIC_GATE
  - source_id: cad_model_specs_v0
    path: 20_engineering/cad/spacecraft_layout/model_specs_v0.json
    sha256: 712f4b6411b241f37676eee3f45813c981ee5699238017cb0bc4bb5fa50d4666
    role: DERIVED_GEOMETRY_CONSUMER
  - source_id: visualization_scene_manifest
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

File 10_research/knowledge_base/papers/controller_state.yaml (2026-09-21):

schema_version: 1
controller: paper-knowledge-orchestrator
controller_version: 1.0.0
authority: DERIVED_NAVIGATION_ONLY
verdict: PAPER_KNOWLEDGE_STATE_BUILT
generated_on: '2026-07-22'
integrity_scope: MANIFEST_METADATA_CARD_STRUCTURE_AND_FILE_PRESENCE; PDF_SHA256_REQUIRES_VALIDATE_FLAG
sources:
  manifest: 50_literature/references/manifest.yaml
  manifest_sha256: b71294069deddef2a088dbc3ec63446f54c7d76f42045ed17a5fb066037913d6
  refs_bib: 50_literature/references/refs.bib
  refs_bib_sha256: e9f6b9ea8cc45e6326463730eff73d8d3bfbed45d386d53e6300bc3ab182f209
  notes_index: 50_literature/references/notes/INDEX.md
  notes_index_sha256: 600ff900072276fe846f0c7b4e46b0691aa1dc29c77d9496b629c166a93dd862
  latest_validation_report: 10_research/knowledge_base/papers/controller_validation.json
counts:
  manifest_entries: 45
  local_pdf_registered: 44
  local_pdf_present: 44
  reading_cards_complete: 34
  pdf_ready_for_reading: 10
  blocked_no_fulltext: 1
  claim_evidence_rows: 0
  reading_status:
    BLOCKED_NO_LOCAL_PDF: 1
    PDF_READY_FOR_READING: 10
    READING_CARD_COMPLETE: 34
  doi_status:
    CROSSREF_NOT_FOUND: 3
    NO_PRIMARY_DOI_STATUS: 7
    VERIFIED: 33
    VERIFIED_AFTER_ADJUDICATION: 2
  mission_line:
    debris_removal: 13
    on_orbit_assembly: 3
    both: 9
    platform_common: 20
blockers:
- bibkey: gerstmayr2013ancfreview
  status: BLOCKED_NO_LOCAL_PDF
  next_action: ACQUIRE_FULLTEXT_UNDER_SOURCE_POLICY
entries:
- manifest_order: 1
  bibkey: rybus2024manipulators
  title: 'Robotic manipulators for in-orbit servicing and active debris removal: Review and comparison'
  year: 2024
  category: survey
  section: V0
  mission_line: both
  grade: A
  priority: P0
  reading_mode:
  - 定调
  - 对标
  doi: 10.1016/j.paerosci.2024.101055
  doi_status: VERIFIED
  archive_status: MANUAL_PDF_VALIDATED
  manifest_pdf_validation: PASS
  local_pdf: 50_literature/pdf/01_survey/rybus2024manipulators.pdf
  local_pdf_status: PRESENT
  reading_card: ''
  reading_status: PDF_READY_FOR_READING
  next_action: DEEP_READ_AND_CREATE_CARD
  why_from_manifest: 臂本体自由度、臂长、质量与末端执行器横向选型的首要表格来源。
  figure_role_from_manifest: 机械臂构型与参数选型对比表
- manifest_order: 2
  bibkey: papadopoulos2021survey
  title: 'Robotic manipulation and capture in space: A survey'
  year: 2021
  category: survey
  section: V0
  mission_line: both
  grade: A
  priority: P0
  reading_mode:
  - 定调
  doi: 10.3389/frobt.2021.686723
  doi_status: VERIFIED
  archive_status: OPEN_ACCESS_DOWNLOADED
  manifest_pdf_validation: PASS
  local_pdf: 50_literature/pdf/01_survey/papadopoulos2021survey.pdf
  local_pdf_status: PRESENT
  reading_card: 50_literature/references/notes/papadopoulos2021survey.md
  reading_status: READING_CARD_COMPLETE
  next_action: REUSE_CARD_AND_RECHECK_LOCATORS_FOR_ACTIVE_CLAIM
  why_from_manifest: 串联动力学建模、规划、捕获与捕获后镇定，建立项目总方法图。
  figure_role_from_manifest: 任务阶段—算法—证据链总览图
- manifest_order: 3
  bibkey: alizadeh2024comprehensive
  title: A comprehensive survey of space robotic manipulators for on-orbit servicing
  year: 2024
  category: survey
  section: V0
  mission_line: both
  grade: A
  priority: P1
  reading_mode:
  - 定调
  - 对标
  doi: 10.3389/frobt.2024.1470950
  doi_status: VERIFIED
  archive_status: OPEN_ACCESS_DOWNLOADED
  manifest_pdf_validation: PASS
  local_pdf: 50_literature/pdf/01_survey/alizadeh2024comprehensive.pdf
  local_pdf_status: PRESENT
  reading_card: 50_literature/references/notes/alizadeh2024comprehensive.md
  reading_status: READING_CARD_COMPLETE
  next_action: REUSE_CARD_AND_RECHECK_LOCATORS_FOR_ACTIVE_CLAIM
  why_from_manifest: 补齐 OSAM-1、SPIDER、Canadarm3 等较新系统进展。
  figure_role_from_manifest: 任务与机械臂系统代际对比图
- manifest_order: 4
  bibkey: sst2024autonomous
  title: Review of Autonomous Space Robotic Manipulators for On-Orbit Servicing and Active Debris Removal
  year: 2025
  category: survey
  section: V0
  mission_line: both
  grade: B
  priority: P1
  reading_mode:
  - 定调
  doi: 10.34133/space.0291
  doi_status: VERIFIED
  archive_status: OPEN_ACCESS_DOWNLOADED
  manifest_pdf_validation: PASS
  local_pdf: 50_literature/pdf/01_survey/sst2024autonomous.pdf
  local_pdf_status: PRESENT
  reading_card: 50_literature/references/notes/sst2024autonomous.md
  reading_status: READING_CARD_COMPLETE
  next_action: REUSE_CARD_AND_RECHECK_LOCATORS_FOR_ACTIVE_CLAIM
  why_from_manifest: 提供自主性分级，用于界定遥操作、技能调度与闭环自主的边界。
  figure_role_from_manifest: 自主等级阶梯图
- manifest_order: 5
  bibkey: zhang2022adcr
  title: Review of On-Orbit Robotic Arm Active Debris Capture Removal Methods
  year: 2022
  category: survey
  section: V0
  mission_line: debris_removal
  grade: B
  priority: P2
  reading_mode:
  - 定调
  doi: 10.3390/aerospace10010013
  doi_status: VERIFIED
  archive_status: OPEN_ACCESS_DOWNLOADED
  manifest_pdf_validation: PASS
  local_pdf: 50_literature/pdf/01_survey/zhang2022adcr.pdf
  local_pdf_status: PRESENT
  reading_card: 50_literature/references/notes/zhang2022adcr.md
  reading_status: READING_CARD_COMPLETE
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

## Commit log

2026-09-21 Publish: 航天服务星具身智能机械臂机器人 / Space Service Robot with Embodied Intelligence
    Repositions the project from a competition entry to an on-orbit-servicing
    space-robotics research programme carried alongside long-term hardware
    development. Competition records are retained as historical evidence only and
    no longer gate engineering acceptance.
    Contents: the complete 12U CubeSat servicing spacecraft digital prototype
    (SolidWorks native + STEP via Git LFS), the mechanical / electrical-harness /
    power-thermal / propulsion design package, and the machine-adjudicated
    free-floating dynamics evidence base.
    New at repository root:
    - README.md bilingual overview: re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
    [00_Master_Skeleton_V2_2.SLDPRT, 01_PROTECTED_PATH_REGISTER.csv, 01_Primary_Structure_V2_.stl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]
2026-09-21 docs: add collaborator quick-start covering the three ways a clone goes wrong
    Verification of collaborator access surfaced three practical blockers that the
    README did not mention. All three are silent failures — nothing errors out,
    the result is just wrong.
    1. Cloning without Git LFS installed yields ~130-byte pointer stubs for every
    CAD file. Filenames all look correct and nothing reports an error, so the
    failure is easy to miss until a file will not open.
    2. A full clone pulls 13 GB and draws on the repository's shared LFS bandwidth
    quota. Exhausting it blocks LFS downloads for everyone, not just the person
    who triggered it. The skip-smudge clone (~256 MB) plus targeted `gi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
2026-09-21 chore: drop 314 committed SolidWorks lock files, ignore them going forward
    SolidWorks writes a ~$<name> stub next to any document it has open. The stub
    holds only the owning user and machine — no design data — and a stale one
    makes SolidWorks report the document as in use by another user. 314 of them
    had been committed (265 .SLDPRT, 48 .SLDASM, 1 .SLD; 126 bytes each, 38 KB
    total), 135 of those in one WP09 cad directory.
    Removed from the index and the working tree, and added `~$*` to .gitignore so
    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
2026-09-21 docs: disambiguate the CURRENT_R2_* series — V8 is not a superset of V3
    Three series in 01_project/competition/ each carry seven files whose names
    claim to be "CURRENT", all sharing as_of_date 2026-08-28. Name, date and
    version number are all insufficient to pick the right one.
    Key-by-key comparison of AUTHORITY_DELTA V2..V8 shows the series is NOT
    purely cumulative: V3 -> V4 drops two top-level keys that no later version
    restores.
    authority_additions_and_navigation_corrections
    unresolved_owner_and_system_bindings
    The second holds five open engineering bindings, all false — 24-solid
    prismatic confirmation, joint1/joint2 travel map, as-built derate, system
    registry revision, produc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

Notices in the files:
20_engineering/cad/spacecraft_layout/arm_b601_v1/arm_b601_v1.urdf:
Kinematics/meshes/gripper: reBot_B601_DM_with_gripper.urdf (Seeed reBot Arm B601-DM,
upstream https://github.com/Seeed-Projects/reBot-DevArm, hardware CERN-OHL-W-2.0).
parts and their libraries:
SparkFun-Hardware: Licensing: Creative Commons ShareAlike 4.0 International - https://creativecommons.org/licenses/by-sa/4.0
